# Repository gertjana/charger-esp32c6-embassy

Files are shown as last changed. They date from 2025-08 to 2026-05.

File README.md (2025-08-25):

# ESP32-C6 Embassy Charged

An ESP32-C6 based electric vehicle charging station built with Embassy async runtime and OCPP 1.6 support.

## Quick Start

### 1. Configuration Setup

Copy the example configuration file and update it with your settings:

```bash
cp app_config.toml.example app_config.toml
```

Edit `app_config.toml` with your actual values:

```toml
[wifi]
ssid = "YOUR_WIFI_NETWORK"
password = "YOUR_WIFI_PASSWORD"

[charger]
name = "esp32c6 charger 001"
model = "ESP32-C6"
vendor = "GA Make"
serial = "esp32c6-charger-001"

[mqtt]
broker = "broker.hivemq.com"
port = 1883
client_id = "esp32c6-charger-001"
```

### 2. Environment Variable Overrides (Optional)

You can override any configuration value using environment variables, the naming i:

```
CHARGER_<section>_key>
for instance CHARGER_WIFI_ID
```

### 3. Build and Flash

```bash
cargo build
cargo run
```

## OCPP Protocol Support

The charger implements OCPP 1.6 protocol:

### Outgoing Messages (Published to `/charger/{serial}`)
- **Authorize**: Sent when a user swipes their card for authorization
- **BootNotification**: Sent once at startup with charger model, vendor and serial details
- **Heartbeat**: Periodic status updates with configurable interval
- **StartTransaction**: Charging session initiation with ID tag and timestamp
- **StopTransaction**: Charging session completion with transaction ID and timestamp

### Responses and incoming Messages (Subscribed to `/system/{serial}`)

## Development

This project uses:
- **Embassy**: Async runtime for embedded Rust with concurrent task management
- **ESP-HAL**: Hardware abstraction for ESP32-C6
- **OCPP-RS**: Open Charge Point Protocol implementation
- **Embassy-Net**: Networking stack with WiFi and MQTT support
- **Rust-MQTT**: Lightweight MQTT client for embedded systems

### Architecture
The system is built around Embassy async tasks:
- **Network Stack**: WiFi connection management and IP configuration
- **MQTT Client**: Bidirectional message of OCPP Messages
- **NTP Client**: Queries NTP Server every 4 hours and syncing with local timer in the ESP32-C6
- **OCPP 1.6**: minimum support for OCPP 1.6 to support basic Charging behaviour
- **Hardware Tasks**: GPIO monitoring for cable detection, card swipes. Led and Relay control and update a small display
- **Periodic Tasks**: for instance Heartbeat transmission and boot notifications (once)

#### Application Diagram

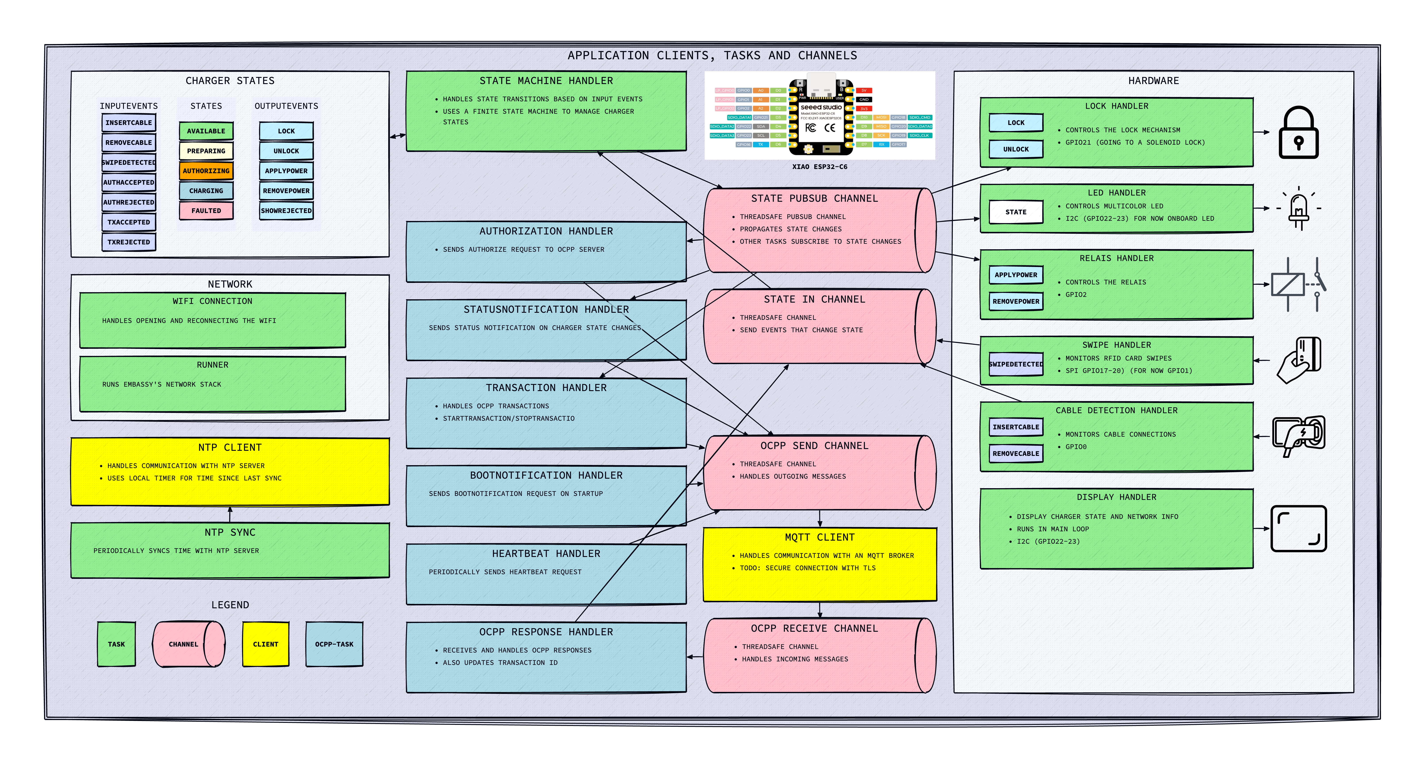
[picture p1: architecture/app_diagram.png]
Application Diagram


#### State Diagram

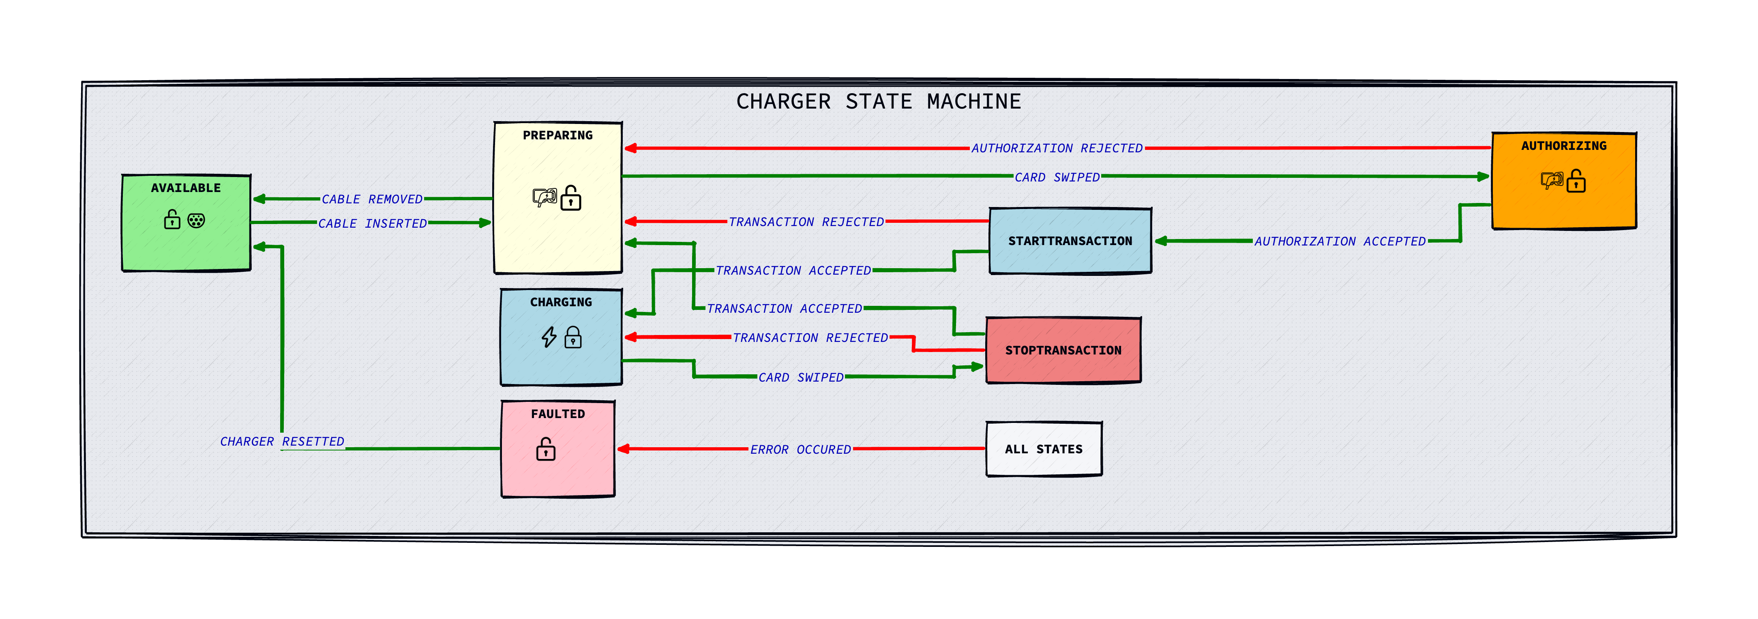
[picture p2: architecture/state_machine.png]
State Diagram


### Memory Management
- **Heap Size**: 64KB allocated for dynamic memory
- **Message Buffers**: 2048-byte capacity for larger OCPP messages
- **Channel Queues**: 5-message capacity for MQTT send/receive operations
- **Static Allocation**: Embassy static cells for zero-allocation async runtime

## Security Note

The `app_config.toml` file contains sensitive information (WiFi passwords, etc.) and is excluded from version control. Always use the `.example` file as a template for new deployments.

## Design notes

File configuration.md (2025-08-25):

## Configuration Reference

### WiFi Settings
- `ssid`: Your WiFi network name
- `password`: Your WiFi network password

### Charger Identity
- `name`: Human-readable charger name for identification
- `model`: Hardware model identifier (default: "ESP32-C6")
- `vendor`: Manufacturer or organization name
- `serial`: Unique serial number for this charger instance

### MQTT Connection
- `broker`: MQTT broker hostname or IP address
- `port`: MQTT broker port (default: 1883)
- `client_id`: Unique identifier for MQTT client connection

The charger automatically generates MQTT topics based on the serial number:
- Publishing topic: `/charger/{serial}`
- Subscription topic: `/system/{serial}`

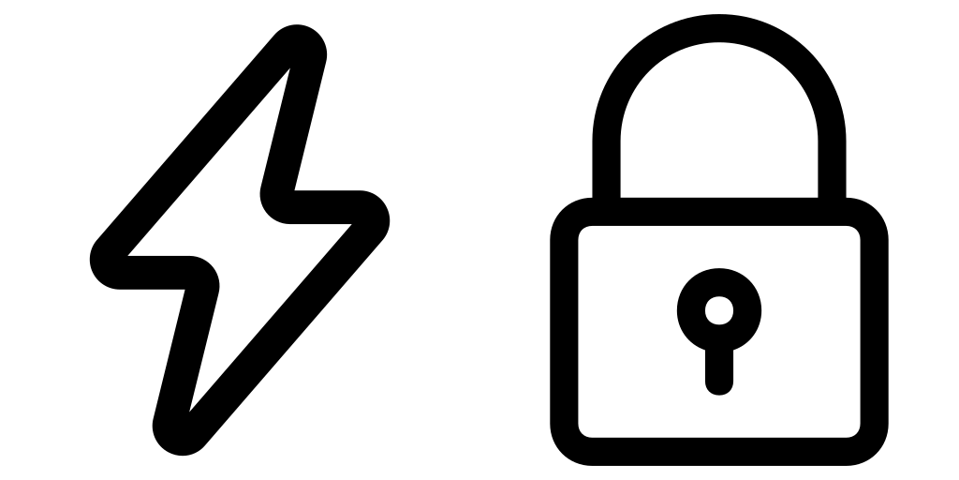
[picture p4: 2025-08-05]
architecture/images/lock+charging.png

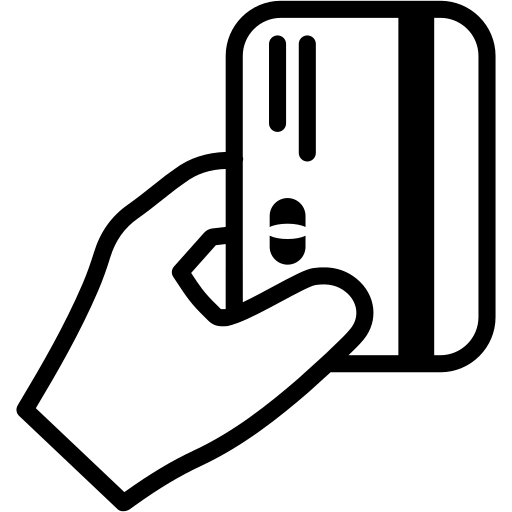
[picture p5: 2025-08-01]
architecture/images/money.png

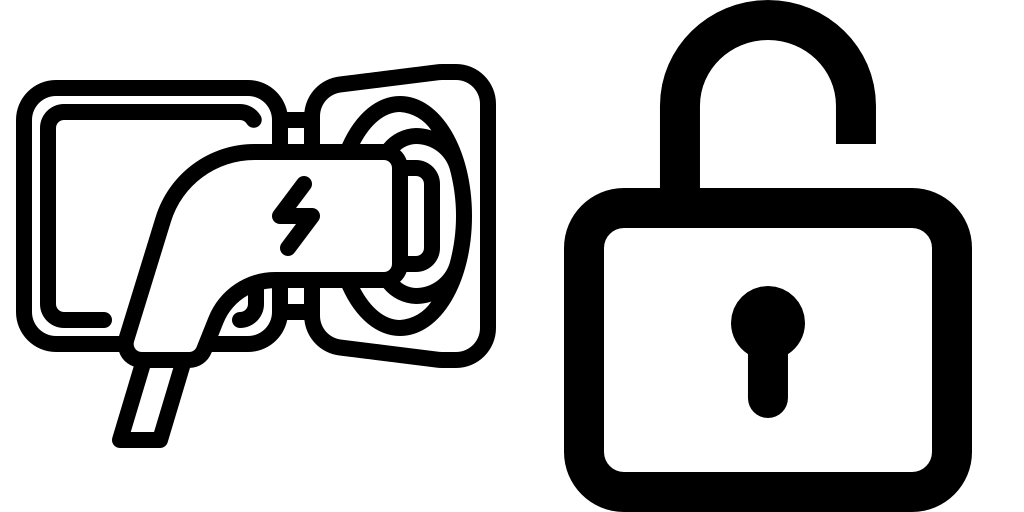
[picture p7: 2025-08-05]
architecture/images/inserted_unlocked.png

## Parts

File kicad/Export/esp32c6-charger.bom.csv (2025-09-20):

Id | Designator | Footprint | Quantity | Designation | Supplier and ref
1 | Display1 | 128x64OLED | 1 | SSD1306
2 | Rfidreader1 | RC522 | 1 | RC522
3 | D1 | LED_WS2812B_PLCC4_5.0x5.0mm_P3.2mm | 1 | WS2812B
4 | U2 | XIAO-ESP32C6-DIP | 1 | XIAO-ESP32-C6
5 | D4 | LED_1206_3216Metric_Pad1.42x1.75mm_HandSolder | 1 | Detect
6 | D3 | LED_1206_3216Metric_Pad1.42x1.75mm_HandSolder | 1 | Lock
7 | R3,R4,R5 | R_1206_3216Metric_Pad1.30x1.75mm_HandSolder | 3 | 68Ω
8 | D2 | LED_1206_3216Metric_Pad1.42x1.75mm_HandSolder | 1 | Relay
9 | Q2,Q1 | TO-92 | 2 | BC337
10 | J1 | TerminalBlock_Phoenix_MKDS-1,5-2-5.08_1x02_P5.08mm_Horizontal | 1 | Conn_01x02_Socket
11 | C1 | CP_EIA-6032-28_Kemet-C | 1 | 10uF
12 | R1,R2 | R_1206_3216Metric_Pad1.30x1.75mm_HandSolder | 2 | 10k
13 | U1 | SOT-223-3_TabPin2 | 1 | AMS1117-5.0
14 | K1 | Relay_SPDT_Omron_G2RL-1-E | 1 | G2RL-1
15 | J2 | TerminalBlock_Phoenix_MKDS-1,5-6-5.08_1x06_P5.08mm_Horizontal | 1 | Power/Lock/Detect
16 | J3 | TerminalBlock_Phoenix_MKDS-1,5-3-5.08_1x03_P5.08mm_Horizontal | 1 | Relay
17 | D5 | D_DO-35_SOD27_P7.62mm_Horizontal | 1 | 1N4148WS
18 | C2 | CP_EIA-6032-28_Kemet-C | 1 | 22uF

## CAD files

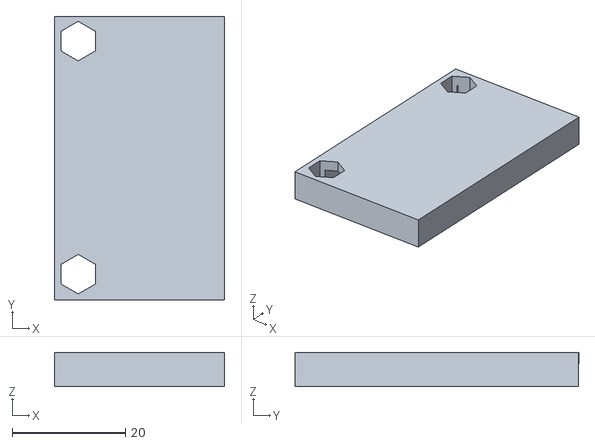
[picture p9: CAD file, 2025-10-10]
kicad/Export/case/Voltage_protection_M3_v2.stl
30.0 x 50.0 x 6.00

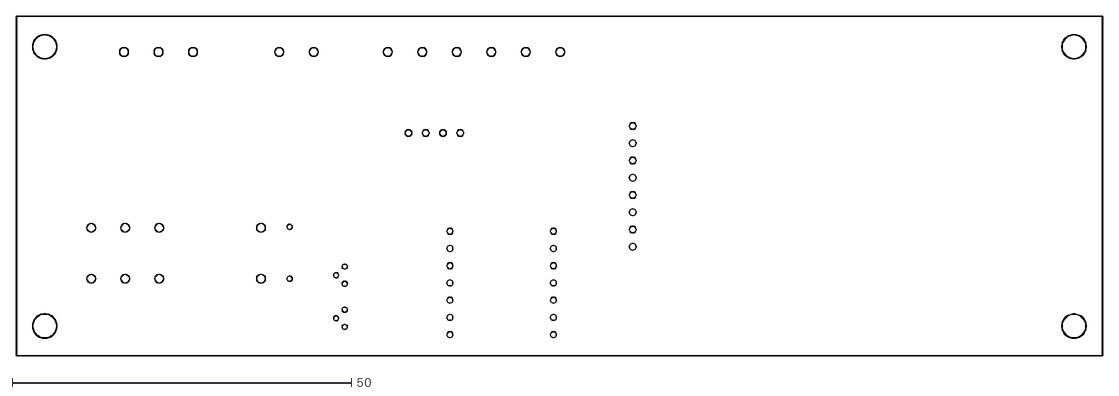
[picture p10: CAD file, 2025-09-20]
kicad/Export/dxf/esp32c6-charger-Edge_Cuts.dxf
160.0 x 50.0

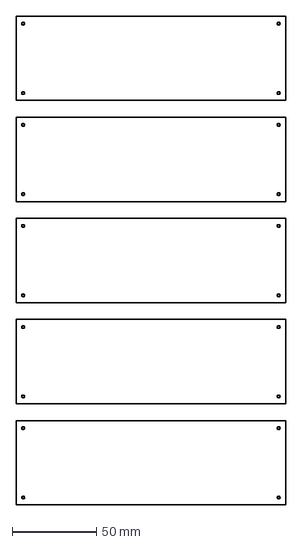
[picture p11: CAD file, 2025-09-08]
kicad/Export/Plexiglas.dxf
160.0 x 290.1 mm

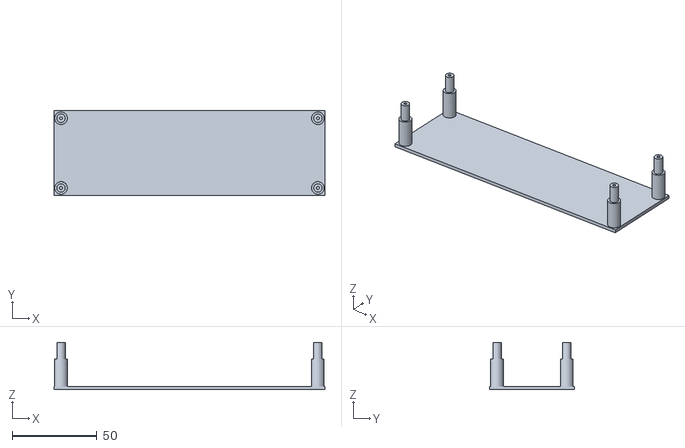
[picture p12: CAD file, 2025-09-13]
kicad/Export/case/Bottom.stl
159.9 x 49.9 x 28.0

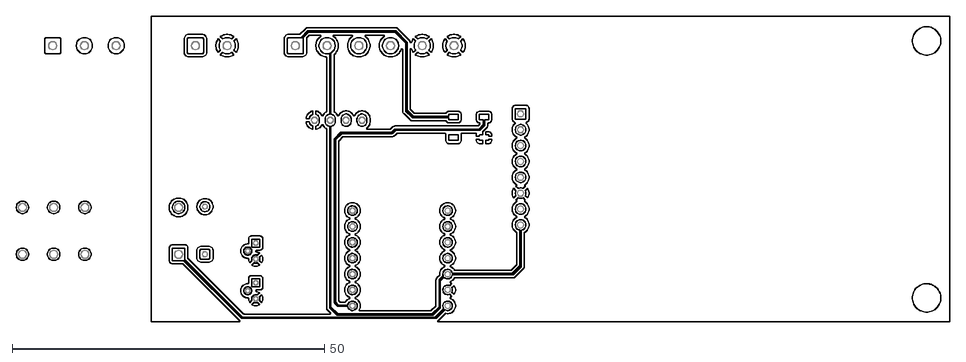
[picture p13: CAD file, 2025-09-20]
kicad/Export/dxf/esp32c6-charger-F_Cu.dxf
149.5 x 49.0

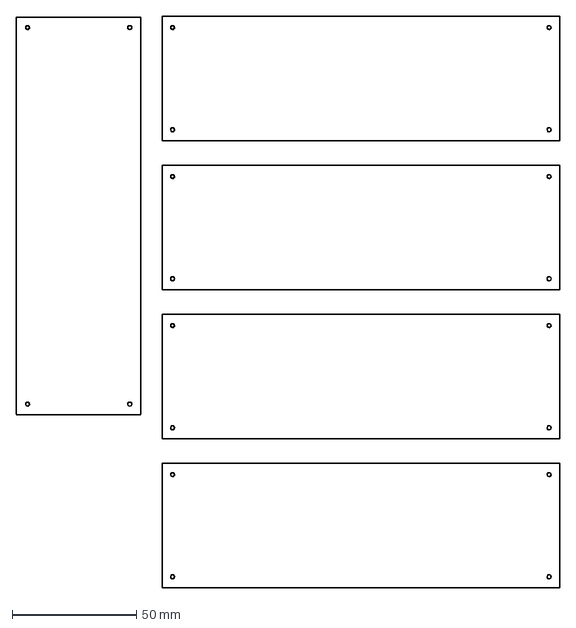
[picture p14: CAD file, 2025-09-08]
kicad/Export/Plexiglas_4+1.dxf
218.7 x 230.1 mm

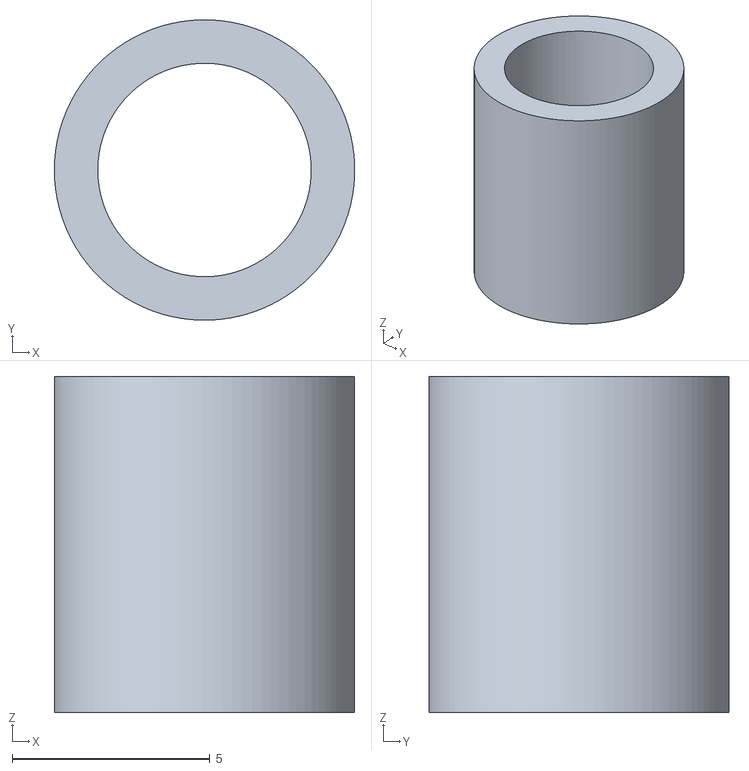
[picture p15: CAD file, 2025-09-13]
kicad/Export/case/Bushel.stl
7.60 x 7.60 x 8.50

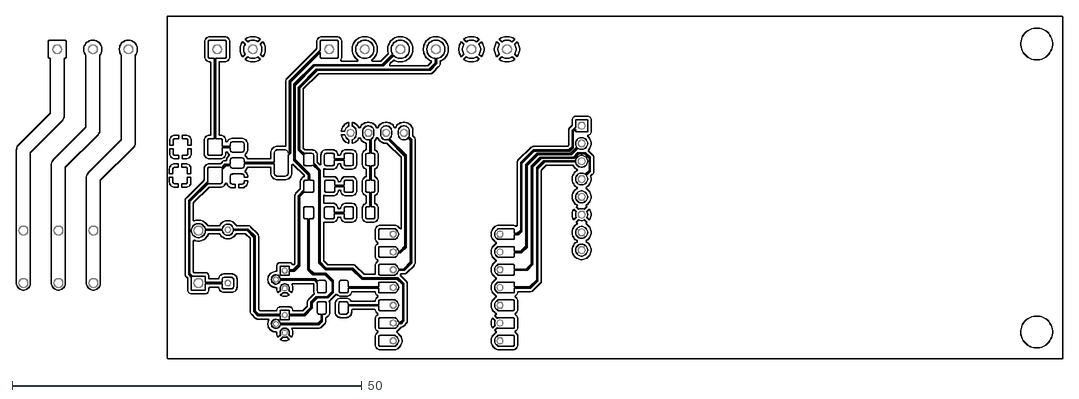
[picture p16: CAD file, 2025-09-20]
kicad/Export/dxf/esp32c6-charger-B_Cu.dxf
149.5 x 49.0

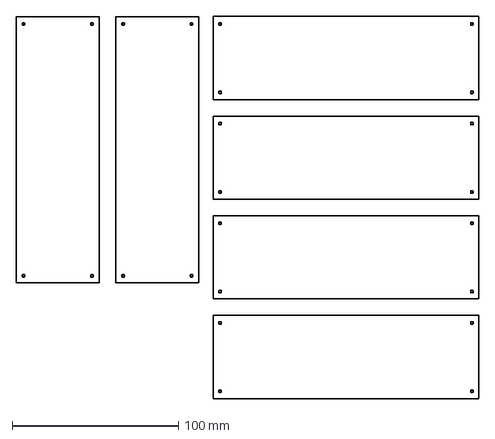
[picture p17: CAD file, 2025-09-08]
kicad/Export/Plexiglas_4+2.dxf
278.7 x 230.1 mm

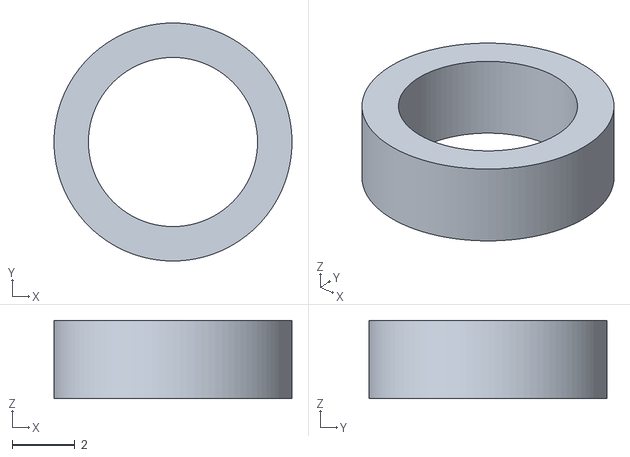
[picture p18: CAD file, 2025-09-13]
kicad/Export/case/ShortBushel.stl
7.60 x 7.60 x 2.50

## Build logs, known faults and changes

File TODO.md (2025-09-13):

# TODO List

## Current

### Tasks

* Include Accept/Reject from Start and StopTransaction responses into the statemachine

### Bugs

* probably same/similar issue:
  * After running for a while (hours), the time shown on the display stops (app halts)
  * WHen time is not synced initially, the next sync halts the application or panics

## Archive

### tasks

* done ~~Subscribe/Receive MQTT messages~~
* done ~~Hook up SSD1306 display~~
* done ~~Use NTP Server to get the current date/time (no_std challenge)~~
* done ~~Time on display in local timezone~~
* done ~~Setup workflow swipe-> AuthorizeReq -> AuthorizeResp -> charging~~
* done ~~Implemented Lock handler~~
* done ~~Refactor de-bouncing into a util method~~
* done ~~set initial states based on cable inserted or not~~
* done ~~Start- and StopTransaction~~
* done ~~Clean up log and make it more consistent~~
* wont do ~~Proper (typesafe) Response Handler~~
* done ~~Implement code for RFID-RC522 SPI Module to do proper charge card swipes~~
* wont do ~~Research if possible: Pass on id_tag with InputEvent~~
* wont do ~~TLS Connection for MQTT~~
* done ~~Don't go to Faulted if no valid transition is found, keep the current state, no outputevents~~

### bugs

* ~~MQTT Topic should be specific for the charger (Id instead of name)~~
* ~~Resetting after error, should also evaluate the hardware to set the correct state~~
* ~~TransactionID doesn't seem to get stored correctly~~
* ~~Don't send StatusNofication on State Authorizing~~

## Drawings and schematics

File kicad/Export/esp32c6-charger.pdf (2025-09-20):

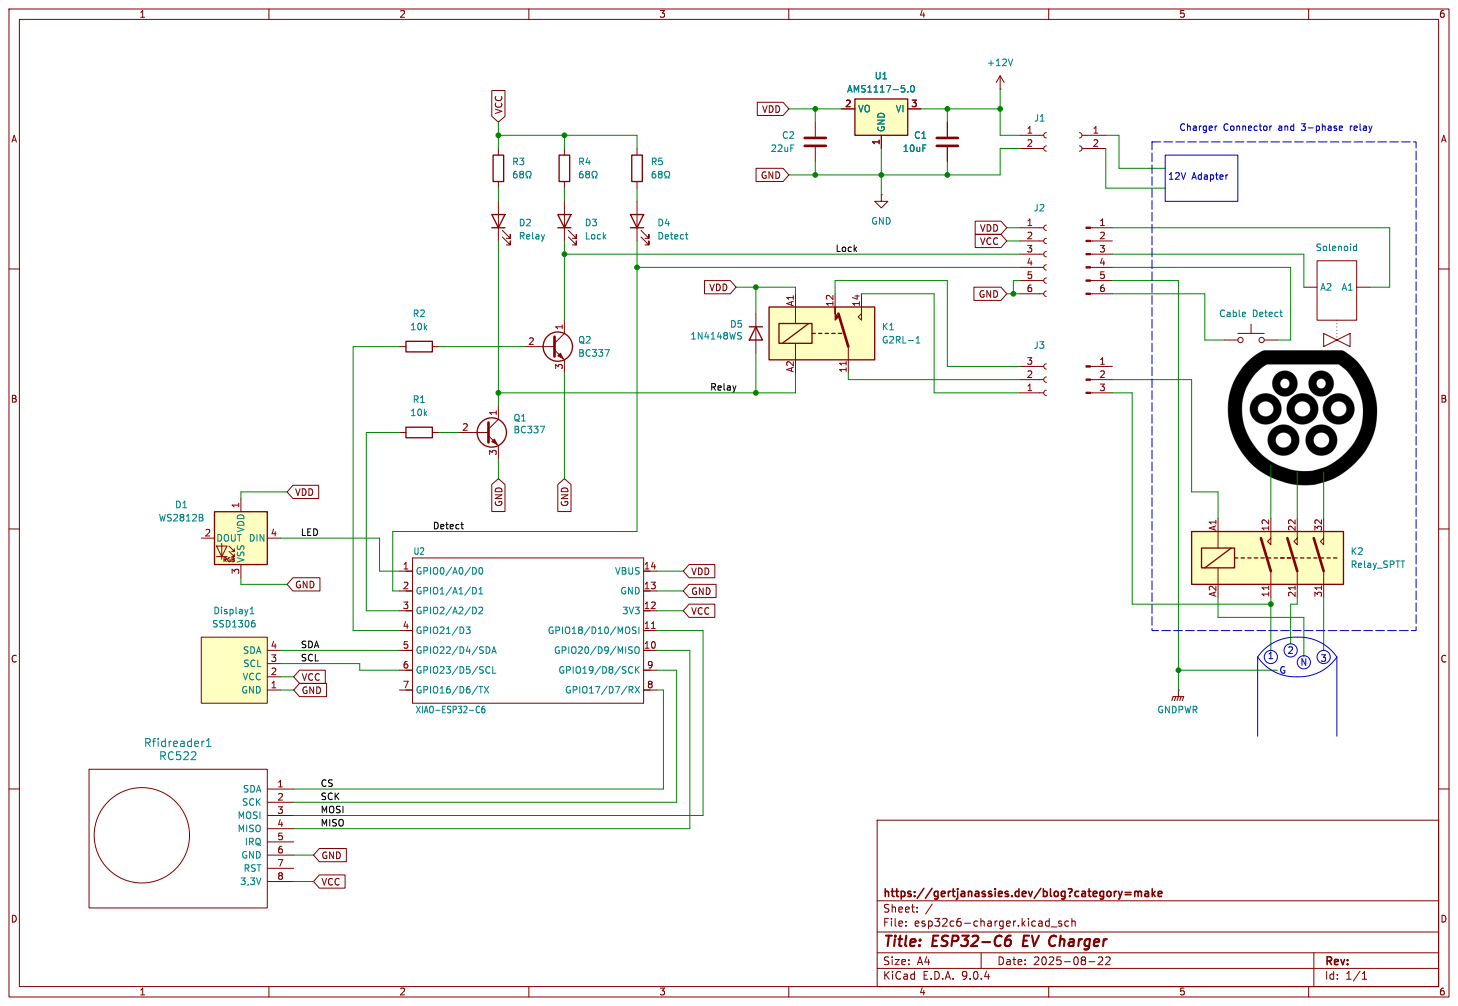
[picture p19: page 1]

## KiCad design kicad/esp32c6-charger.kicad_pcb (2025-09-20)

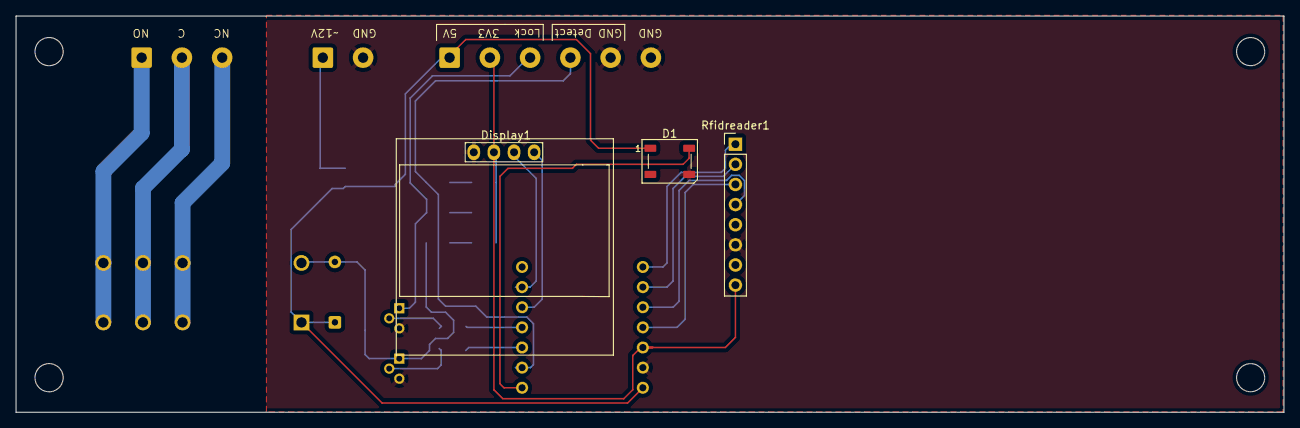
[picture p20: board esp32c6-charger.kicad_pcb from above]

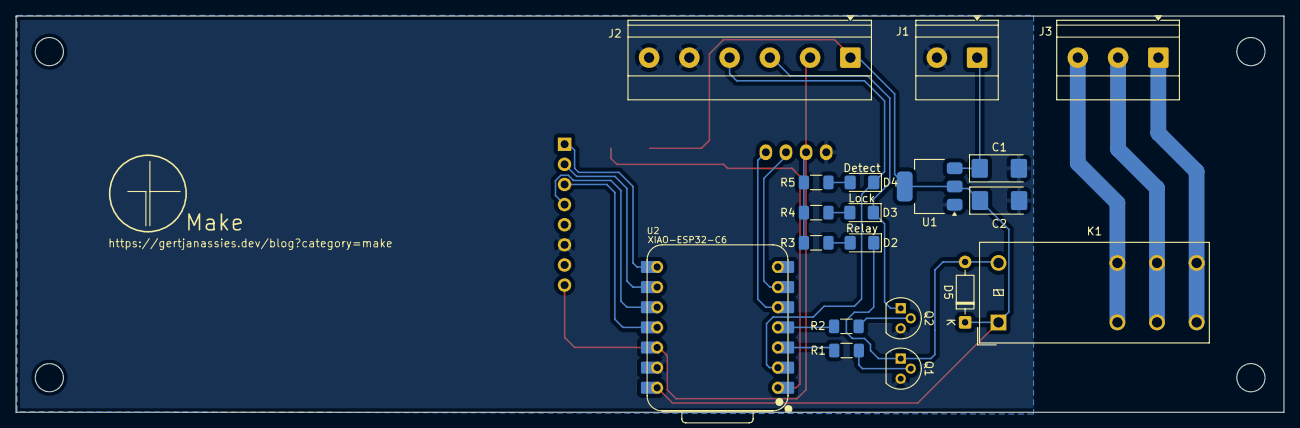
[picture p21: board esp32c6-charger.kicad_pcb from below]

Board: 2 copper layers, 160.0 x 50.0 mm, 22 parts (19 on the bottom side), 24 nets.

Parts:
C1: 10uF; CP_EIA-6032-28_Kemet-C
C2: 22uF; CP_EIA-6032-28_Kemet-C
D1: WS2812B; LED_WS2812B_PLCC4_5.0x5.0mm_P3.2mm
D2: Relay; LED_1206_3216Metric_Pad1.42x1.75mm_HandSolder
D3: Lock; LED_1206_3216Metric_Pad1.42x1.75mm_HandSolder
D4: Detect; LED_1206_3216Metric_Pad1.42x1.75mm_HandSolder
D5: 1N4148WS; D_DO-35_SOD27_P7.62mm_Horizontal
Display1: SSD1306; 128x64OLED
J1: Conn_01x02_Socket; TerminalBlock_Phoenix_MKDS-1,5-2-5.08_1x02_P5.08mm_Horizont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
J2: Power/Lock/Detect; TerminalBlock_Phoenix_MKDS-1,5-6-5.08_1x06_P5.08mm_Horizont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
J3: Relay; TerminalBlock_Phoenix_MKDS-1,5-3-5.08_1x03_P5.08mm_Horizont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
K1: G2RL-1; Relay_SPDT_Omron_G2RL-1-E
Q1, Q2: BC337; TO-92
R1, R2: 10k; R_1206_3216Metric_Pad1.30x1.75mm_HandSolder
R3, R4, R5: 68Ω; R_1206_3216Metric_Pad1.30x1.75mm_HandSolder
Rfidreader1: RC522
U1: AMS1117-5.0; SOT-223-3_TabPin2
U2: XIAO-ESP32-C6; XIAO-ESP32C6-DIP

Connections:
+12V: C1.1, J1.1, U1.3 (VI)
/CS: Rfidreader1.1 (SDA), U2.8 (GPIO17/D7/RX)
/Detect: D4.1 (K), J2.4, U2.2 (GPIO1/A1/D1)
/LED: D1.4 (DIN), U2.1 (GPIO0/A0/D0)
/Lock: D3.1 (K), J2.3, Q2.1 (C)
/MISO: Rfidreader1.4 (MISO), U2.10 (GPIO20/D9/MISO)
/MOSI: Rfidreader1.3 (MOSI), U2.11 (GPIO18/D10/MOSI)
/Relay: D2.1 (K), D5.2 (A), K1.A2, Q1.1 (C)
/SCK: Rfidreader1.2 (SCK), U2.9 (GPIO19/D8/SCK)
/SCL: Display1.3 (SCL), U2.6 (GPIO23/D5/SCL)
/SDA: Display1.4 (SDA), U2.5 (GPIO22/D4/SDA)
GND: C1.2, C2.2, D1.3 (VSS), Display1.1 (GND), J1.2, J2.5, J2.6, Q1.3 (E), Q2.3 (E), Rfidreader1.6 (GND), U1.1 (GND), U2.13 (GND)
unnamed: D2.2 (A), R3.1
unnamed: D3.2 (A), R4.1
unnamed: D4.2 (A), R5.1
unnamed: J3.1, K1.14
unnamed: J3.2, K1.11
unnamed: J3.3, K1.12
unnamed: Q1.2 (B), R1.2
unnamed: Q2.2 (B), R2.2
unnamed: R1.1, U2.3 (GPIO2/A2/D2)
unnamed: R2.1, U2.4 (GPIO21/D3)
VCC: Display1.2 (VCC), J2.2, R3.2, R4.2, R5.2, Rfidreader1.8 (3,3V), U2.12 (3V3)
VDD: C2.1, D1.1 (VDD), D5.1 (K), J2.1, K1.A1, U1.2 (VO), U2.14 (VBUS)

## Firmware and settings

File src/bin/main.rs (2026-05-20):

#![no_std]
#![no_main]

extern crate alloc;
use embassy_executor::Spawner;
use embassy_net::tcp::TcpSocket;
use embassy_time::{Duration, Instant, Timer};
use embedded_hal_bus::spi::ExclusiveDevice;
use esp32c6_embassy_charged::{
    charger::{self, Charger, ChargerState, InputEvent, OutputEvent},
    config::Config,
    mk_static, mqtt,
    network::{self, NetworkStack},
    ntp, ocpp, utils,
};
use esp_hal::{
    clock::CpuClock,
    delay::Delay,
    gpio::{Input, InputConfig, Level, Output, OutputConfig, Pull},
    i2c::master::{Config as I2cConfig, I2c},
    rmt::Rmt,
    spi::{self, master::Spi},
    time::Rate,
    timer::{systimer::SystemTimer, timg::TimerGroup},
    Blocking,
};

use esp_hal_smartled::{smart_led_buffer, SmartLedsAdapter};
use smart_leds::{
    brightness,
    colors::{BLUE, GREEN, ORANGE, RED, WHITE},
    SmartLedsWrite as _, RGB8,
};

use log::{info, warn};
use mfrc522::{comm::blocking::spi::SpiInterface, Mfrc522};
use rust_mqtt::client::client::MqttClient;
use rust_mqtt::utils::rng_generator::CountingRng;

#[panic_handler]
fn panic(_: &core::panic::PanicInfo) -> ! {
    loop {}
}

// This creates a default app-descriptor required by the esp-idf bootloader.
// For more information see: <https://docs.espressif.com/projects/esp-idf/en/stable/esp32/api-reference/system/app_image_format.html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>
esp_bootloader_esp_idf::esp_app_desc!();

#[esp_hal_embassy::main]
async fn main(spawner: Spawner) {
    // generator version: 0.5.0

    esp_println::logger::init_logger_from_env();

    let config = esp_hal::Config::default().with_cpu_clock(CpuClock::max());
    let peripherals = esp_hal::init(config);

    esp_alloc::heap_allocator!(size: 64 * 1024);

    let timer0 = SystemTimer::new(peripherals.SYSTIMER);
    esp_hal_embassy::init(timer0.alarm0);

    info!("MAIN: Charger initialized!");

    let rng = esp_hal::rng::Rng::new(peripherals.RNG);
    let timer1 = TimerGroup::new(peripherals.TIMG0);

    // I2C Setup
    let i2c = I2c::new(peripherals.I2C0, I2cConfig::default())
        .unwrap()
        .into_async()
        .with_sda(peripherals.GPIO22)
        .with_scl(peripherals.GPIO23);

    // Initialize SSD1306 display
    info!("MAIN: Initializing SSD1306 display...");
    let mut display_manager: Option<esp32c6_embassy_charged::display::DisplayManager<_>> =
        match esp32c6_embassy_charged::display::DisplayManager::new(i2c) {
            Ok(mut display) => {
                info!("Display initialized successfully");

                // Draw the startup logo
                match display.draw_logo() {
                    Ok(()) => {
                        info!("MAIN: Logo displayed successfully");
                    }
                    Err(e) => {
                        warn!("MAIN: Failed to draw logo: {e}");
                    }
                }
                Some(display)
            }
            Err(e) => {
                warn!("MAIN: Failed to initialize display: {e}");
                warn!("MAIN: Continuing without display functionality");
                None
            }
        };

    let charger_led = mk_static!(
        SmartLedsAdapter<esp_hal::rmt::ConstChannelAccess<esp_hal::rmt::Tx, 0>, 25>,
        {
            let frequency = Rate::from_mhz(80);
            let rmt = Rmt::new(peripherals.RMT, frequency).expect("Failed to initialize RMT0");
            SmartLedsAdapter::new(rmt.channel0, peripherals.GPIO0, smart_led_buffer!(1))
        }
    );

    let cable_lock_pin = Output::new(peripherals.GPIO21, Level::Low, Default::default());

    let cable_switch = Input::new(
        peripherals.GPIO1,
        InputConfig::default().with_pull(Pull::Up),
    );

    // SPI Cardreader setup
    let spi_bus  = // mk_static!(Spi<Blocking>,
        Spi::new(
            peripherals.SPI2,
            spi::master::Config::default()
                .with_frequency(Rate::from_mhz(5))
                .with_mode(spi::Mode::_0),
        )
        .unwrap()
        .with_sck(peripherals.GPIO19)
        .with_mosi(peripherals.GPIO18)
        .with_miso(peripherals.GPIO20);
    // );

    let sd_cs = //mk_static!(Output,
        Output::new(peripherals.GPIO17, Level::High, OutputConfig::default());
    // );

    let charger_relay = Output::new(peripherals.GPIO2, Level::Low, Default::default());

    let charger = mk_static!(Charger, Charger::new());

    match cable_switch.is_low() {
        true => {
            info!("MAIN: Cable is connected, setting initial state to Preparing");
            charger.set_state(ChargerState::Preparing).await;
        }
        false => {
            info!("Cable is not connected, setting initial state to Available");
            charger.set_state(ChargerState::Available).await;
        }
    }

    // Publish initial state to PubSub
    let initial_publisher = charger::STATE_PUBSUB.publisher().unwrap();
    initial_publisher.publish_immediate((ChargerState::Available, heapless::Vec::new()));

    // Load configuration from TOML file with environment variable overrides
    let config = Config::from_config();
    info!(
        "MAIN: Charger configuration loaded: {}",
        config.charger_name
    );

    // Store values we need before config is moved
    let ntp_server = config.ntp_server;

    info!("MAIN: Initializing network stack...");
    let network =
        network::NetworkStack::init(&spawner, timer1, rng, peripherals.WIFI, config).await;
    let network = mk_static!(NetworkStack, network);

    info!("MAIN: Waiting for network connection...");
    network.wait_for_ip().await;
    info!("MAIN: Network connected successfully");

    // Start hardware-related tasks (can run independently of network)
    spawner.spawn(charger_led_task(charger_led, charger)).ok();

    spawner.spawn(cable_lock_task(cable_lock_pin)).ok();

    spawner.spawn(charger_cable_task(cable_switch)).ok();

    spawner.spawn(card_swipe_task(spi_bus, sd_cs, charger)).ok();

    spawner.spawn(charger_relay_task(charger_relay)).ok();

    spawner
        .spawn(charger::statemachine_handler_task(charger))
        .ok();

    spawner
        .spawn(charger::authorization_timeout_task(charger))
        .ok();

    // Perform initial NTP time synchronization
    info!("MAIN: Synchronizing time with NTP server...");
    let mut sync_attempts = 0;
    let max_sync_attempts = 3;

    while !ntp::is_time_synced() && sync_attempts < max_sync_attempts {
        sync_attempts += 1;
        info!("MAIN: NTP sync attempt {sync_attempts} of {max_sync_attempts}");

        match ntp::sync_time_with_ntp(network, ntp_server).await {
            Ok(()) => {
                info!("MAIN: NTP: Initial time synchronization successful");
                info!("MAIN: NTP: Current time: {}", ntp::get_iso8601_time());
                info!("MAIN: NTP: Timing info: {}", ntp::get_timing_info());
                break;
            }
            Err(e) => {
                warn!("MAIN: NTP: Sync attempt {sync_attempts} failed: {e}");
                if sync_attempts < max_sync_attempts {
                    Timer::after(Duration::from_secs(5)).await;
                }
            }
        }
    }

    if !ntp::is_time_synced() {
        warn!(
            "MAIN: NTP: Failed to synchronize time after {max_sync_attempts} attempts, continuing anyway",
        );
    }

    // Now start network-dependent tasks
    info!("MAIN: Creating MQTT client...");
    let rx_buffer = mk_static!([u8; 2048], [0; 2048]);
    let tx_buffer = mk_static!([u8; 2048], [0; 2048]);
    let write_buffer = mk_static!([u8; 2048], [0; 2048]);
    let recv_buffer = mk_static!([u8; 2048], [0; 2048]);

    match mqtt::create_mqtt_client(network, rx_buffer, tx_buffer, write_buffer, recv_buffer).await {
        Ok(client) => {
            info!("MAIN: MQTT client created successfully");
            let client = mk_static!(
                MqttClient<'static, TcpSocket<'static>, 5, CountingRng>,
                client
            );
            spawner.spawn(mqtt::mqtt_client_task(network, client)).ok();

            // Only start NTP sync task after MQTT client is successfully created
            spawner.spawn(ntp::ntp_sync_task(network)).ok();
        }
        Err(e) => {
            warn!("MAIN: Failed to create MQTT client: {e:?}");
            // Could spawn a retry task here if needed
        }
    }

    // Start OCPP-related tasks
    spawner.spawn(ocpp::response_handler_task(charger)).ok();

    spawner.spawn(ocpp::heartbeat_task()).ok();

    spawner.spawn(ocpp::boot_notification_task()).ok();

    spawner.spawn(ocpp::status_notification_task(charger)).ok();

    spawner.spawn(ocpp::authorize_task(charger)).ok();

    spawner.spawn(ocpp::transaction_handler_task(charger)).ok();

    let mut old_state = charger.get_state().await;
    let mut last_display_update = Instant::now();

    info!("MAIN: Starting main loop...");
    loop {
        if let Some(ref mut display) = display_manager {
            if last_display_update.elapsed() >= Duration::from_millis(900) {
                let temp_config = Config::from_config();
                match display.update_display(&temp_config, network, old_state) {
                    Ok(()) => {
                        // Display updated successfully
                    }
                    Err(e) => {
                        warn!("MAIN: Failed to update display: {e}");
                    }
                }
                last_display_update = Instant::now();
            }
        }

        let current_state = charger.get_state().await;
        if current_state != old_state {
            info!("MAIN: Charger state changed: {}", current_state.as_str());
            old_state = current_state;
        }
        Timer::after(Duration::from_millis(100)).await;
    }
}

/// Maps charger states to corresponding LED colors
fn get_led_color_for_state(state: ChargerState) -> Option<RGB8> {
    match state {
        ChargerState::Off => None,                 // LED off
        ChargerState::Available => Some(GREEN),    // Green = Ready to charge
        ChargerState::Preparing => Some(WHITE),    // White = Preparing to charge
        ChargerState::Charging => Some(BLUE),      // Blue = Charging in progress
        ChargerState::Authorizing => Some(ORANGE), // Orange = Authorizing user
        ChargerState::Faulted => Some(RED),        // Red = Error/fault condition
    }
}

/// Task to control the WS2812B RGB LED based on the charging state
#[embassy_executor::task]
async fn charger_led_task(
    charger_led: &'static mut SmartLedsAdapter<
        esp_hal::rmt::ConstChannelAccess<esp_hal::rmt::Tx, 0>,
        25,
    >,
    charger: &'static Charger,
) {
    info!("TASK: Started WS2812B RGB LED Charger Status Indicator");

    // Set initial LED color based on current charger state
    let initial_state = charger.get_state().await;
    info!(
        "LED: Setting initial color for state: {}",
        initial_state.as_str()
    );

    match get_led_color_for_state(initial_state) {
        Some(color) => {
            let brightness_level = 20; // Adjust brightness (0-255)
            info!(
                "LED: Initial color RGB({}, {}, {}) for state: {}",
                color.r,
                color.g,
                color.b,
                initial_state.as_str()
            );

            if let Err(e) = charger_led.write(brightness([color].into_iter(), brightness_level)) {
                warn!("LED: Failed to set initial color: {e:?}");
            }
        }
        None => {
            // Turn off LED for Off state
            info!(
                "LED: Turning off LED for initial state: {}",
                initial_state.as_str()
            );
            let off_color = RGB8::new(0, 0, 0);
            if let Err(e) = charger_led.write([off_color]) {
                warn!("LED: Failed to turn off LED initially: {e:?}");
            }
        }
    }

    let mut subscriber = charger::STATE_PUBSUB.subscriber().unwrap();

    loop {
        // Wait for state changes via PubSub
        if let embassy_sync::pubsub::WaitResult::Message((current_state, _)) =
            subscriber.next_message().await
        {
            info!("LED: Charger state changed to: {}", current_state.as_str());

            match get_led_color_for_state(current_state) {
                Some(color) => {
                    let brightness_level = 20; // Adjust brightness (0-255)
                    info!(
                        "LED: Setting color RGB({}, {}, {}) for state: {}",
                        color.r,
                        color.g,
                        color.b,
                        current_state.as_str()
                    );

                    if let Err(e) =
                        charger_led.write(brightness([color].into_iter(), brightness_level))
                    {
                        warn!("LED: Failed to set color: {e:?}");
                    }
                }
                None => {
                    // Turn off LED for Off state
                    info!("LED: Turning off LED for state: {}", current_state.as_str());
                    let off_color = RGB8::new(0, 0, 0);
                    if let Err(e) = charger_led.write([off_color]) {
                        warn!("LED: Failed to turn off LED: {e:?}");
                    }
                }
            }
        }
    }
}

/// Task to detect charger cable connection and disconnection
#[embassy_executor::task]
async fn charger_cable_task(mut button: Input<'static>) {
    info!("TASK: Started Charger cable Detector");

    loop {
        button.wait_for_any_edge().await;

        Timer::after(Duration::from_millis(300)).await; // Debounce delay
        let new_state = button.is_low();

        // Send the appropriate event based on the new state
        let cable_event = if new_state {
            InputEvent::InsertCable
        } else {
            InputEvent::RemoveCable
        };

        info!("CBLE: Detected stable event: {cable_event:?}, sending to state machine");
        charger::STATE_IN_CHANNEL.send(cable_event).await;
    }
}

/// Task to control the charger relay based on the charging state
#[embassy_executor::task]
async fn charger_relay_task(mut relay: Output<'static>) {
    info!("TASK: Started Charger relay control");

    let mut subscriber = charger::STATE_PUBSUB.subscriber().unwrap();

    relay.set_low();
    info!("RLAY: Initial state set to low (off)");

    loop {
        // Wait for state changes via PubSub
        if let embassy_sync::pubsub::WaitResult::Message((current_state, output_events)) =
            subscriber.next_message().await
        {
            // Simple logic: turn on relay when charging, off otherwise
            match current_state {
                ChargerState::Charging if output_events.contains(&OutputEvent::ApplyPower) => {
                    info!("RLAY: Setting relay high (on)");
                    relay.set_high();
                }
                _ => {
                    info!("RLAY: Setting relay low (off)");
                    relay.set_low();
                }
            }
        }
    }
}

/// Task to control the cable lock based on the charging state
#[embassy_executor::task]
async fn cable_lock_task(mut cable_lock_pin: Output<'static>) {
    info!("TASK: Started Cable Lock Control");
    let mut subscriber = charger::STATE_PUBSUB.subscriber().unwrap();

    loop {
        if let embassy_sync::pubsub::WaitResult::Message((current_state, output_events)) =
            subscriber.next_message().await
        {
            match current_state {
                _ if output_events.contains(&OutputEvent::Lock) => {
                    info!("LOCK: Locking cable for charging state");
                    cable_lock_pin.set_high();
                }
                _ if output_events.contains(&OutputEvent::Unlock) => {
                    info!(
                        "LOCK: Unlocking cable for state: {}",
                        current_state.as_str()
                    );
                    cable_lock_pin.set_low();
                }
                _ => {
                    info!("LOCK: No action for state: {}", current_state.as_str());
                }
            }
        }
    }
}

/// Task to handle card swipe events using the MFRC522 RFID reader
#[embassy_executor::task]
async fn card_swipe_task(
    spi_bus: Spi<'static, Blocking>,
    sd_cs: Output<'static>,
    charger: &'static Charger,
) {
    info!("TASK: Started Card Swipe Detector");

    let delay = Delay::new();
    let spi_dev = ExclusiveDevice::new(spi_bus, sd_cs, delay).unwrap();
    let spi_interface = SpiInterface::new(spi_dev);
    let mut rfid_reader = Mfrc522::new(spi_interface).init().unwrap();

    loop {
        if let Ok(atqa) = rfid_reader.reqa() {
            info!("RFID: Card swipe detected");
            Timer::after(Duration::from_millis(50)).await;
            if let Ok(uid) = rfid_reader.select(&atqa) {
                let hex = utils::bytes_to_hex_string::<24>(uid.as_bytes());
                info!("RFID: UID {hex}");

                charger.set_id_tag(&hex).await;

                charger::STATE_IN_CHANNEL
                    .send(InputEvent::SwipeDetected)
                    .await;
                Timer::after(Duration::from_millis(500)).await;
            }
        }

        Timer::after(Duration::from_secs(1)).await;
    }
}

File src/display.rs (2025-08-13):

use core::fmt::Write;
use embedded_graphics::{
    mono_font::{
        ascii::{FONT_10X20, FONT_6X10},
        MonoTextStyleBuilder,
    },
    pixelcolor::BinaryColor,
    prelude::*,
    primitives::{Circle, Line, PrimitiveStyleBuilder},
    text::{Baseline, Text},
};
use log::info;
use ssd1306::{prelude::*, I2CDisplayInterface, Ssd1306};

use crate::{charger::ChargerState, config::Config, network::NetworkStack};

/// Display manager for SSD1306 OLED display
pub struct DisplayManager<I2C> {
    display: Ssd1306<
        I2CInterface<I2C>,
        DisplaySize128x64,
        ssd1306::mode::BufferedGraphicsMode<DisplaySize128x64>,
    >,
}

impl<I2C> DisplayManager<I2C>
where
    I2C: embedded_hal::i2c::I2c,
{
    /// Initialize the SSD1306 display
    pub fn new(i2c: I2C) -> Result<Self, &'static str> {
        info!("DISP:Initializing SSD1306 display...");

        let display_addr = 0x3C;

        // Try to initialize with the detected address
        info!("DISP: Trying I2C address 0x{display_addr:02X}...");
        let interface = I2CDisplayInterface::new_custom_address(i2c, display_addr);

        let mut display = Ssd1306::new(interface, DisplaySize128x64, DisplayRotation::Rotate0)
            .into_buffered_graphics_mode();
        info!("Created display object, attempting init() with address 0x{display_addr:02X}...");

        match display.init() {
            Ok(()) => {
                info!("DISP: Display init() completed successfully with address 0x{display_addr:02X}!");
            }
            Err(_) => {
                info!("DISP: Failed to initialize display at address 0x{display_addr:02X}");
                return Err("Failed to initialize display - device responded but init failed");
            }
        }

        // Clear the display and flush
        display.flush().map_err(|_| "Failed to flush display")?;
        info!("DISP: Display cleared and flushed successfully");

        info!("DISP: SSD1306 display initialized successfully");

        Ok(DisplayManager { display })
    }

    /// Update the display with current charger information
    pub fn update_display(
        &mut self,
        config: &Config,
        network: &NetworkStack,
        charger_state: ChargerState,
    ) -> Result<(), &'static str> {
        // Clear the display buffer
        self.display.clear_buffer();

        let text_style = MonoTextStyleBuilder::new()
            .font(&FONT_6X10)
            .text_color(BinaryColor::On)
            .build();

        // Line 1: Serial number
        let mut serial_line = heapless::String::<21>::new();
        if config.charger_serial.len() > 20 {
            let _ = write!(serial_line, "{}...", &config.charger_serial[..17]);
        } else {
            let _ = write!(serial_line, "{}", config.charger_serial);
        }

        Text::with_baseline(&serial_line, Point::new(0, 0), text_style, Baseline::Top)
            .draw(&mut self.display)
            .map_err(|_| "Failed to draw serial")?;

        // horizontal line
        let stroke_style = PrimitiveStyleBuilder::new()
            .stroke_color(BinaryColor::On)
            .stroke_width(1)
            .build();

        let left_line = Line::new(
            Point::new(0, 12),   // Start point
            Point::new(128, 12), // End point
        );
        left_line
            .into_styled(stroke_style)
            .draw(&mut self.display)
            .map_err(|_| "Failed to draw left line")?;

        // Line 2: Current state in a full-width rectangle with inverted text and larger font
        let state_text = charger_state.as_str();
        // Using larger FONT_10X20 which is approximately 2x the size of FONT_6X10
        let char_width = 10; // Width per character for FONT_10X20

        // Create a rectangle style for the state background
        let rect_style = PrimitiveStyleBuilder::new()
            .fill_color(BinaryColor::On)
            .stroke_color(BinaryColor::On)
            .stroke_width(1)
            .build();

        // Full width rectangle
        let display_width = 128;

        // Use Rectangle for the full width of the display
        let state_rect = embedded_graphics::primitives::Rectangle::new(
            Point::new(0, 16),            // Starts at left edge, positioned below header line
            Size::new(display_width, 22), // Full width of display, height for the larger font
        )
        .into_styled(rect_style);

        state_rect
            .draw(&mut self.display)
            .map_err(|_| "Failed to draw state background")?;

        // Inverted text style for the state with larger font
        let inverted_text_style = MonoTextStyleBuilder::new()
            .font(&FONT_10X20) // Using the larger font
            .text_color(BinaryColor::Off) // Inverted color
            .build();

        // Calculate the center position for the text
        let text_width = state_text.len() as i32 * char_width;
        let center_x = (display_width as i32 - text_width) / 2;

        // Draw the state text - centered in the rectangle
        Text::with_baseline(
            state_text,
            Point::new(center_x, 16), // Centered horizontally, same vertical position
            inverted_text_style,
            Baseline::Top,
        )
        .draw(&mut self.display)
        .map_err(|_| "Failed to draw state")?;

        // horizontal line0
        let stroke_style = PrimitiveStyleBuilder::new()
            .stroke_color(BinaryColor::On)
            .stroke_width(1)
            .build();

        let left_line = Line::new(
            Point::new(0, 40),   // Start point
            Point::new(128, 40), // End point
        );
        left_line
            .into_styled(stroke_style)
            .draw(&mut self.display)
            .map_err(|_| "Failed to draw left line")?;

        // Line 4: IP Address
        let mut ip_line = heapless::String::<21>::new();
        if let Some(ip) = network.get_ip_address() {
            let _ = write!(ip_line, "{ip}");
        } else {
            let _ = write!(ip_line, "Not Connected");
        }

        Text::with_baseline(&ip_line, Point::new(0, 46), text_style, Baseline::Top) // Moved down 4 pixels
            .draw(&mut self.display)
            .map_err(|_| "Failed to draw IP address")?;

        // Line 5: Current local time (if NTP is synced)
        let mut time_line = heapless::String::<21>::new();
        if crate::ntp::is_time_synced() {
            let local_time = crate::ntp::get_local_time_formatted(config.timezone_offset_hours);
            let local_date = crate::ntp::get_local_date_formatted(config.timezone_offset_hours);
            let _ = write!(time_line, "{local_date} {local_time}");
        } else {
            let _ = write!(time_line, "Time Not Synced");
        }

        Text::with_baseline(&time_line, Point::new(0, 56), text_style, Baseline::Top) // Moved down 4 pixels
            .draw(&mut self.display)
            .map_err(|_| "Failed to draw time")?;
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

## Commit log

2025-07-21 basic setup for an embassy project with wifi workingt and a blinking led
2025-07-25 Wired up the charger with tasks to handle it, got basic MQTT Sending working
2025-07-26 Pleasing the linting gods, or in this case fmt and clippy
2025-07-27 Added Config file for all the 'configurables' added thread safe incrementing id for ocpp messages
2025-07-28 feat: Revamped the MQTT Section to use Embassy Channels to avoid deadlocks and implemented Heartbeat and BootNotification Messages
    [main.rs]
2025-07-30 feat: Now support receiving of mqtt messages, fixed buffer sizes to accomodate larger mqtt messages. now using charger serial in the mqtt topics
    [main.rs]
2025-07-31 now uses the local times to calculate the offset from the last ntp sync to keep the date/time current (the timer drift a couple of minutes a day
    [main.rs]
2025-08-03 Added SSD1306 I2C Display showing serial, ip, state and time
2025-08-04 fixed up some merge conflicts
    [display.rs, main.rs]
2025-08-05 added esp32 image and some small updates
2025-08-06 Got Avail -> Occupied -> Authorizing -> Charging flow working
2025-08-07 Added cable lock handler and made all gpio input tasks more resistent to bouncing
2025-08-09 reverted debounce mechanism to a time delay again, works better
    [display.rs, main.rs]
2025-08-14 added start of kicad schematic/pcb
    [esp32c6-charger.kicad_pcb, esp32c6-charger.kicad_sch]
2025-08-15 running pre-commit fixed some things
    [esp32c6-charger.kicad_pcb, esp32c6-charger.kicad_sch]
2025-08-20 moved some of the configuration to it's own file
    [esp32c6-charger-B_Cu.dxf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]
2025-08-20 ignoring bunch of kicad files
    [esp32c6-charger-B_Cu.dxf, esp32c6-charger-Edge_Cuts.dxf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]
2025-08-20 small updates to schema and pcb
2025-08-21 small updates to schema and pcbç√çç
2025-08-21 added external power possibility
    [esp32c6-charger-B_Cu.dxf, esp32c6-charger-Edge_Cuts.dxf, esp32c6-charger-F_Cu.dxf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]
2025-08-24 updated changes to schematic and pcb
    [esp32c6-charger-B_Cu.dxf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]
2025-08-24 small changes and a pdf of the schematic in the export jobset
    [esp32c6-charger-B_Cu.dxf, esp32c6-charger-Edge_Cuts.dxf, esp32c6-charger-F_Cu.dxf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]
2025-08-24 cleaned up Export Jobset
    [esp32c6-charger-B_Cu.dxf, esp32c6-charger-Edge_Cuts.dxf, esp32c6-charger-F_Cu.dxf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]
2025-08-29 updated 3d model for relay
    [esp32c6-charger.kicad_pcb, esp32c6-charger.kicad_sch]
2025-09-02 small changes to copper
    [esp32c6-charger.kicad_pcb]
2025-09-08 Latest exports of all pcb artifacts
    [Bottom.stl, Bushel.stl, Plexiglas.dxf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]
2025-09-08 removed gerber zip
2025-09-13 Got the WS2818B Led working
2025-09-13 updated 3d printable case
    [Bottom.stl, Bushel.stl, ShortBushel.stl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]
2025-09-13 moved local reference to smart-leds to a github one
2025-09-13 used normal transistors and diodes instead of SMD ones, we have the space, why make soldering life more difficult
    [esp32c6-charger-B_Cu.dxf, esp32c6-charger-Edge_Cuts.dxf, esp32c6-charger-F_Cu.dxf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]
2025-09-20 THT Transistors instead of SMT, export jobs now include solder masks and automatically zips them up
    [esp32c6-charger-B_Cu.dxf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]
2025-10-10 Small updates
    [VoltageProtection.stl, Voltage_protection_M3_v2.stl]
2025-10-10 Now reverts back to Preparing State if the Authorizing state does not get a timely respond from the backend
    [main.rs]
2026-05-20 Implemented Accept/Reject for Transactions, starts charging, then stops when StartTransaction is rejected
2026-05-20 To be explicit also added the TxAccepted case, where nothing needs to happen
